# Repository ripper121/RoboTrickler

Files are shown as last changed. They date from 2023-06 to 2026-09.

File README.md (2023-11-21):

# RoboTrickler
 
If you like it, spend me a coffee :)

### Donation: [Paypal](https://www.paypal.com/donate/?hosted_button_id=UHZEEUSTRAF88) (paypal.me/ripper121)

### Full Manual: [Wiki](https://github.com/ripper121/RoboTrickler/wiki)

At the moment only in German, but DeepL will help you ;)

### Latest Release: [Download](https://github.com/ripper121/RoboTrickler/releases/latest)

Youtube:

youtube video (https://www.youtube.com/watch?v=XJgkiJFMUQI)

# License

## creative commons

# Attribution-NonCommercial-ShareAlike 4.0 International

Creative Commons Corporation (“Creative Commons”) is not a law firm and does not provide legal services or legal advice. Distribution of Creative Commons public licenses does not create a lawyer-client or other relationship. Creative Commons makes its licenses and related information available on an “as-is” basis. Creative Commons gives no warranties regarding its licenses, any material licensed under their terms and conditions, or any related information. Creative Commons disclaims all liability for damages resulting from their use to the fullest extent possible.

### Using Creative Commons Public Licenses

Creative Commons public licenses provide a standard set of terms and conditions that creators and other rights holders may use to share original works of authorship and other material subject to copyright and certain other rights specified in the public license below. The following considerations are for informational purposes only, are not exhaustive, and do not form part of our licenses.

* __Considerations for licensors:__ Our public licenses are intended for use by those authorized to give the public permission to use material in ways otherwise restricted by copyright and certain other rights. Our licenses are irrevocable. Licensors should read and understand the terms and conditions of the license they choose before applying it. Licensors should also secure all rights necessary before applying our licenses so that the public can reuse the material as expected. Licensors should clearly mark any material not subject to the license. This includes other CC-licensed material, or material used under an exception or limitation to copyright. [More considerations for licensors](http://wiki.creativecommons.org/Considerations_for_licensors_and_licensees#Considerations_for_licensors).

* __Considerations for the public:__ By using one of our public licenses, a licensor grants the public permission to use the licensed material under specified terms and conditions. If the licensor’s permission is not necessary for any reason–for example, because of any applicable exception or limitation to copyright–then that use is not regulated by the license. Our licenses grant only permissions under copyright and certain other rights that a licensor has authority to grant. Use of the licensed material may still be restricted for other reasons, including because others have copyright or other rights in the material. A licensor may make special requests, such as asking that all changes be marked or described. Although not required by our licenses, you are encouraged to respect those requests where reasonable. [More considerations for the public](http://wiki.creativecommons.org/Considerations_for_licensors_and_licensees#Considerations_for_licensees).

## Creative Commons Attribution-NonCommercial-ShareAlike 4.0 International Public License

By exercising the Licensed Rights (defined below), You accept and agree to be bound by the terms and conditions of this Creative Commons Attribution-NonCommercial-ShareAlike 4.0 International Public License ("Public License"). To the extent this Public License may be interpreted as a contract, You are granted the Licensed Rights in consideration of Your acceptance of these terms and conditions, and the Licensor grants You such rights in consideration of benefits the Licensor receives from making the Licensed Material available under these terms and conditions.

### Section 1 – Definitions.

a. __Adapted Material__ means material subject to Copyright and Similar Rights that is derived from or based upon the Licensed Material and in which the Licensed Material is translated, altered, arranged, transformed, or otherwise modified in a manner requiring permission under the Copyright and Similar Rights held by the Licensor. For purposes of this Public License, where the Licensed Material is a musical work, performance, or sound recording, Adapted Material is always produced where the Licensed Material is synched in timed relation with a moving image.

b. __Adapter's License__ means the license You apply to Your Copyright and Similar Rights in Your contributions to Adapted Material in accordance with the terms and conditions of this Public License.

c. __BY-NC-SA Compatible License__ means a license listed at [creativecommons.org/compatiblelicenses](http://creativecommons.org/compatiblelicenses), approved by Creative Commons as essentially the equivalent of this Public License.

d. __Copyright and Similar Rights__ means copyright and/or similar rights closely related to copyright including, without limitation, performance, broadcast, sound recording, and Sui Generis Database Rights, without regard to how the rights are labeled or categorized. For purposes of this Public License, the rights specified in Section 2(b)(1)-(2) are not Copyright and Similar Rights.

e. __Effective Technological Measures__ means those measures that, in the absence of proper authority, may not be circumvented under laws fulfilling obligations under Article 11 of the WIPO Copyright Treaty adopted on December 20, 1996, and/or similar international agreements.

f. __Exceptions and Limitations__ means fair use, fair dealing, and/or any other exception or limitation to Copyright and Similar Rights that applies to Your use of the Licensed Material.

g. __License Elements__ means the license attributes listed in the name of a Creative Commons Public License. The License Elements of this Public License are Attribution, NonCommercial, and ShareAlike.

h. __Licensed Material__ means the artistic or literary work, database, or other material to which the Licensor applied this Public License.

i. __Licensed Rights__ means the rights granted to You subject to the terms and conditions of this Public License, which are limited to all Copyright and Similar Rights that apply to Your use of the Licensed Material and that the Licensor has authority to license.

j. __Licensor__ means the individual(s) or entity(ies) granting rights under this Public License.

k. __NonCommercial__ means not primarily intended for or directed towards commercial advantage or monetary compensation. For purposes of this Public License, the exchange of the Licensed Material for other material subject to Copyright and Similar Rights by digital file-sharing or similar means is NonCommercial provided there is no payment of monetary compensation in connection with the exchange.

l. __Share__ means to provide material to the public by any means or process that requires permission under the Licensed Rights, such as reproduction, public display, public performance, distribution, dissemination, communication, or importation, and to make material available to the public including in ways that members of the public may access the material from a place and at a time individually chosen by them.

m. __Sui Generis Database Rights__ means rights other than copyright resulting from Directive 96/9/EC of the European Parliament and of the Council of 11 March 1996 on the legal protection of databases, as amended and/or succeeded, as well as other essentially equivalent rights anywhere in the world.

n. __You__ means the individual or entity exercising the Licensed Rights under this Public License. Your has a corresponding meaning.

### Section 2 – Scope.

a. ___License grant.___

   1. Subject to the terms and conditions of this Public License, the Licensor hereby grants You a worldwide, royalty-free, non-sublicensable, non-exclusive, irrevocable license to exercise the Licensed Rights in the Licensed Material to:

        A. reproduce and Share the Licensed Material, in whole or in part, for NonCommercial purposes only; and

        B. produce, reproduce, and Share Adapted Material for NonCommercial purposes only.

   2. __Exceptions and Limitations.__ For the avoidance of doubt, where Exceptions and Limitations apply to Your use, this Public License does not apply, and You do not need to comply with its terms and conditions.

   3. __Term.__ The term of this Public License is specified in Section 6(a).

   4. __Media and formats; technical modifications allowed.__ The Licensor authorizes You to exercise the Licensed Rights in all media and formats whether now known or hereafter created, and to make technical modifications necessary to do so. The Licensor waives and/or agrees not to assert any right or authority to forbid You from making technical modifications necessary to exercise the Licensed Rights, including technical modifications necessary to circumvent Effective Technological Measures. For purposes of this Public License, simply making modifications authorized by this Section 2(a)(4) never produces Adapted Material.

   5. __Downstream recipients.__

        A. __Offer from the Licensor – Licensed Material.__ Every recipient of the Licensed Material automatically receives an offer from the Licensor to exercise the Licensed Rights under the terms and conditions of this Public License.

        B. __Additional offer from the Licensor – Adapted Material.__ Every recipient of Adapted Material from You automatically receives an offer from the Licensor to exercise the Licensed Rights in the Adapted Material under the conditions of the Adapter’s License You apply.

        C. __No downstream restrictions.__ You may not offer or impose any additional or different terms or conditions on, or apply any Effective Technological Measures to, the Licensed Material if doing so restricts exercise of the Licensed Rights by any recipient of the Licensed Material.

   6. __No endorsement.__ Nothing in this Public License constitutes or may be construed as permission to assert or imply that You are, or that Your use of the Licensed Material is, connected with, or sponsored, endorsed, or granted official status by, the Licensor or others designated to receive attribution as provided in Section 3(a)(1)(A)(i).

b. ___Other rights.___

   1. Moral rights, such as the right of integrity, are not licensed under this Public License, nor are publicity, privacy, and/or other similar personality rights; however, to the extent possible, the Licensor waives and/or agrees not to assert any such rights held by the Licensor to the limited extent necessary to allow You to exercise the Licensed Rights, but not otherwise.

   2. Patent and trademark rights are not licensed under this Public License.

   3. To the extent possible, the Licensor waives any right to collect royalties from You for the exercise of the Licensed Rights, whether directly or through a collecting society under any voluntary or waivable statutory or compulsory licensing scheme. In all other cases the Licensor expressly reserves any right to collect such royalties, including when the Licensed Material is used other than for NonCommercial purposes.

### Section 3 – License Conditions.

Your exercise of the Licensed Rights is expressly made subject to the following conditions.

a. ___Attribution.___

   1. If You Share the Licensed Material (including in modified form), You must:

       A. retain the following if it is supplied by the Licensor with the Licensed Material:

         i. identification of the creator(s) of the Licensed Material and any others designated to receive attribution, in any reasonable manner requested by the Licensor (including by pseudonym if designated);

         ii. a copyright notice;

         iii. a notice that refers to this Public License;

         iv. a notice that refers to the disclaimer of warranties;

         v. a URI or hyperlink to the Licensed Material to the extent reasonably practicable;

       B. indicate if You modified the Licensed Material and retain an indication of any previous modifications; and

       C. indicate the Licensed Material is licensed under this Public License, and include the text of, or the URI or hyperlink to, this Public License.

   2. You may satisfy the conditions in Section 3(a)(1) in any reasonable manner based on the medium, means, and context in which You Share the Licensed Material. For example, it may be reasonable to satisfy the conditions by providing a URI or hyperlink to a resource that includes the required information.

   3. If requested by the Licensor, You must remove any of the information required by Section 3(a)(1)(A) to the extent reasonably practicable.

b. ___ShareAlike.___

In addition to the conditions in Section 3(a), if You Share Adapted Material You produce, the following conditions also apply.

1. The Adapter’s License You apply must be a Creative Commons license with the same License Elements, this version or later, or a BY-NC-SA Compatible License.

2. You must include the text of, or the URI or hyperlink to, the Adapter's License You apply. You may satisfy this condition in any reasonable manner based on the medium, means, and context in which You Share Adapted Material.

3. You may not offer or impose any additional or different terms or conditions on, or apply any Effective Technological Measures to, Adapted Material that restrict exercise of the rights granted under the Adapter's License You apply.

### Section 4 – Sui Generis Database Rights.

Where the Licensed Rights include Sui Generis Database Rights that apply to Your use of the Licensed Material:

a. for the avoidance of doubt, Section 2(a)(1) grants You the right to extract, reuse, reproduce, and Share all or a substantial portion of the contents of the database for NonCommercial purposes only;

b. if You include all or a substantial portion of the database contents in a database in which You have Sui Generis Database Rights, then the database in which You have Sui Generis Database Rights (but not its individual contents) is Adapted Material, including for purposes of Section 3(b); and

c. You must comply with the conditions in Section 3(a) if You Share all or a substantial portion of the contents of the database.

For the avoidance of doubt, this Section 4 supplements and does not replace Your obligations under this Public License where the Licensed Rights include other Copyright and Similar Rights.

### Section 5 – Disclaimer of Warranties and Limitation of Liability.

a. __Unless otherwise separately undertaken by the Licensor, to the extent possible, the Licensor offers the Licensed Material as-is and as-available, and makes no representations or warranties of any kind concerning the Licensed Material, whether express, implied, statutory, or other. This includes, without limitation, warranties of title, merchantability, fitness for a particular purpose, non-infringement, absence of latent or other defects, accuracy, or the presence or absence of errors, whether or not known or discoverable. Where disclaimers of warranties are not allowed in full or in part, this disclaimer may not apply to You.__

b. __To the extent possible, in no event will the Licensor be liable to You on any legal theory (including, without limitation, negligence) or otherwise for any direct, special, indirect, incidental, consequential, punitive, exemplary, or other losses, costs, expenses, or damages arising out of this Public License or use of the Licensed Material, even if the Licensor has been advised of the possibility of such losses, costs, expenses, or damages. Where a limitation of liability is not allowed in full or in part, this limitation may not apply to You.__

c. The disclaimer of warranties and limitation of liability provided above shall be interpreted in a manner that, to the extent possible, most closely approximates an absolute disclaimer and waiver of all liability.

### Section 6 – Term and Termination.

a. This Public License applies for the term of the Copyright and Similar Rights licensed here. However, if You fail to comply with this Public License, then Your rights under this Public License terminate automatically.

b. Where Your right to use the Licensed Material has terminated under Section 6(a), it reinstates:

   1. automatically as of the date the violation is cured, provided it is cured within 30 days of Your discovery of the violation; or

   2. upon express reinstatement by the Licensor.

   For the avoidance of doubt, this Section 6(b) does not affect any right the Licensor may have to seek remedies for Your violations of this Public License.

c. For the avoidance of doubt, the Licensor may also offer the Licensed Material under separate terms or conditions or stop distributing the Licensed Material at any time; however, doing so will not terminate this Public License.

d. Sections 1, 5, 6, 7, and 8 survive termination of this Public License.

### Section 7 – Other Terms and Conditions.

a. The Licensor shall not be bound by any additional or different terms or conditions communicated by You unless expressly agreed.

b. Any arrangements, understandings, or agreements regarding the Licensed Material not stated herein are separate from and independent of the terms and conditions of this Public License.

### Section 8 – Interpretation.

a. For the avoidance of doubt, this Public License does not, and shall not be interpreted to, reduce, limit, restrict, or impose conditions on any use of the Licensed Material that could lawfully be made without permission under this Public License.

b. To the extent possible, if any provision of this Public License is deemed unenforceable, it shall be automatically reformed to the minimum extent necessary to make it enforceable. If the provision cannot be reformed, it shall be severed from this Public License without affecting the enforceability of the remaining terms and conditions.

c. No term or condition of this Public License will be waived and no failure to comply consented to unless expressly agreed to by the Licensor.

d. Nothing in this Public License constitutes or may be interpreted as a limitation upon, or waiver of, any privileges and immunities that apply to the Licensor or You, including from the legal processes of any jurisdiction or authority.

> Creative Commons is not a party to its public licenses. Notwithstanding, Creative Commons may elect to apply one of its public licenses to material it publishes and in those instances will be considered the “Licensor.” The text of the Creative Commons public licenses is dedicated to the public domain under the CC0 Public Domain Dedication. Except for the limited purpose of indicating that material is shared under a Creative Commons public license or as otherwise permitted by the Creative Commons policies published at creativecommons.org/policies, Creative Commons does not authorize the use of the trademark “Creative Commons” or any other trademark or logo of Creative Commons without its prior written consent including, without limitation, in connection with any unauthorized modifications to any of its public licenses or any other arrangements, understandings, or agreements concerning use of licensed material. For the avoidance of doubt, this paragraph does not form part of the public licenses.
>
> Creative Commons may be contacted at creativecommons.org

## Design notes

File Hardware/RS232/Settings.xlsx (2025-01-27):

 | G&G | Steinberg | KERN | Sartorius 9PIN | Sartorius 25PIN | Acculab 25PIN | A&D
RS_1 |  |  |  |  |  |  | X
RS_2 | X | X | X | X | X | X
RS_3_R |  |  |  |  |  |  | X
RS_3_L | X | X | X | X | X | X
RS_4 |  |  |  |  |  |  | X
RS_5 | X | X | X | X | X | X
RXD | L | L | R | L | R | R | L
TXD | R | R | L | R | L | L | R
Connector | Male | Male | Male | Female | Female | Female | Female

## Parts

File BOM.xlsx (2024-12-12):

Menge | Bezeichnung | Bezugsquelle
1 | MKS DLC32-TS35 | https://www.amazon.de/KOOKYE-Printer-TS35-R-Offline-Controller/dp/B09N3HH27T
1 | MKS TS35 | https://www.amazon.de/KOOKYE-Controller-engraving-Alternate-versions/dp/B09J21K33F
1 | A4988 | https://shop.strenuous.dev/Motor-Treiber-A4988/P8
1 | MKS DLC32 Enclosure or 3D Print | https://www.aliexpress.com/item/32872172334.html
2 | Rillenkugellager 6900RS 10mmx22mmx6mm | https://www.amazon.de/sourcing-map-Rillenkugellager-10mmx22mmx6mm-Kohlenstoffstahl/dp/B07H5J1JD6
1 | Nema 17 Schrittmotor 42x23mm | https://www.amazon.de/dp/B08FFKZLYH
1 | Alurohr 10x 8 x 160mm | https://shop.strenuous.dev/Alurohr-160mm/P15
1 | 12 V DC 2 A 24 W Netzteil | https://www.amazon.de/dp/B01G0Q3RWU
1 | 4 Pin Dupont / Jumper Kabel female | https://shop.strenuous.dev/RS232-Kabel/P11
1 | RS232 TTL Konverter Stecker | https://shop.strenuous.dev/RS232-Stecker/P19.11
5 | M3 x 6mm | https://shop.strenuous.dev/M3x6-Linsenkopf-Schraube/P14
1 | 3D Druckteile | https://shop.strenuous.dev/3D-Druck-Teile/P16
 | Komplett Bausatz | https://shop.strenuous.dev/Robo-Trickler/P1.2 | 175.00 €
 | Fertig aufgebaut & Getesetet | https://shop.strenuous.dev/Robo-Trickler/P1.1 | 275.00 €
 | Passende Waagen:
 | G&G PLC 100 | https://waage-shop.com/PLC-Feinwaagen-Tischwaage-Praezisionswaagen | 115.00 €
 | G&G JJ100B Empfehlung für schnelles Trickeln | https://waage-shop.com/JJ-B-Praezisionwaage-Laborwaage-JJ100B-110g-0001g | 240.00 €
 | Oder jede ander mit RS232

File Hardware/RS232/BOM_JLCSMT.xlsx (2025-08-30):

Comment | Designator | Footprint | JLCPCB Part #（optional）
1000uF | C5 | 140CLH-1010 | C72469
RED | RXD | CHIP-LED0603 | C2286
B6B-PH-K-S(LF)(SN) | TTL | Through Hole,P=2mm | C131342
GREEN | TXD | CHIP-LED0603 | C2286
1k | R1,R2 | R0402 | C11702
100n | C1,C2,C3,C4 | C0402 | C1525
SP3232EEN-L/TR | U1 | SOIC127P600X175-16N | C13482
PINHD-2X3 | JP1 | 2X03 | C65114
Amphenol ICC LD09P13A4GX00LF | RS232 | D-Sub | C3118153

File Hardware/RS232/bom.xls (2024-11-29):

Comment | Designator | Footprint | JLCPCB Part #
RED | RXD | CHIP-LED0603 | C2286
PINHD-1X4/90 | TTL | 1X04/90 | C492412
GREEN | TXD | CHIP-LED0603 | C72043
1k | R1,R2 | R0402 | C11702
SP3232EEN-L/TR | U1 | SOIC127P600X175-16N | C13482
100n | C1,C2,C3,C4 | C0402 | C1525
PINHD-2X3 | JP1 | 2X03 | C7501274
AmphenolICCLD09P13A4GX00LF | RS232 | D-Sub | C3103673

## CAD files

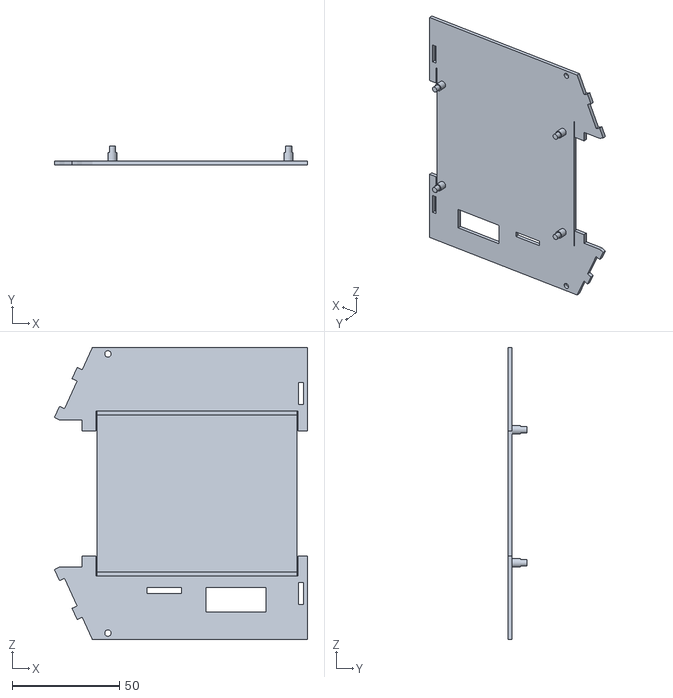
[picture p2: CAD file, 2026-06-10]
Hardware/CAD/Housing/Main.stl
118.0 x 9.00 x 136.0

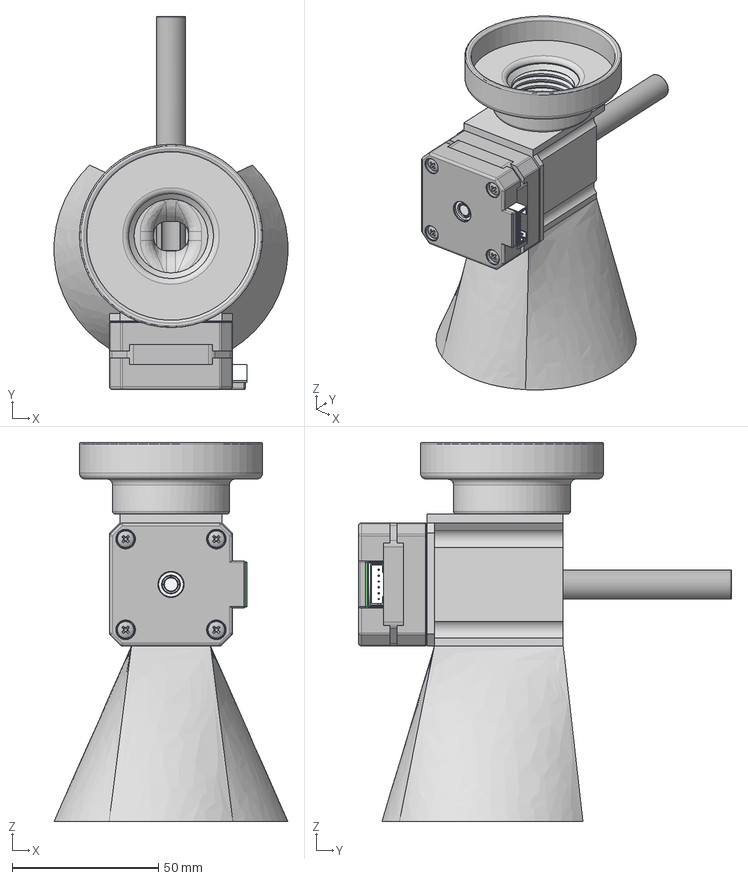
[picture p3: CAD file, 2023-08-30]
3D-Files/Trickler_Full.step
79.9 x 127.6 x 129.5 mm
61900-2rs1 x 2
M3x12-Screw
M3x12-Screw004
M3x12-Screw005
M3x12-Screw006

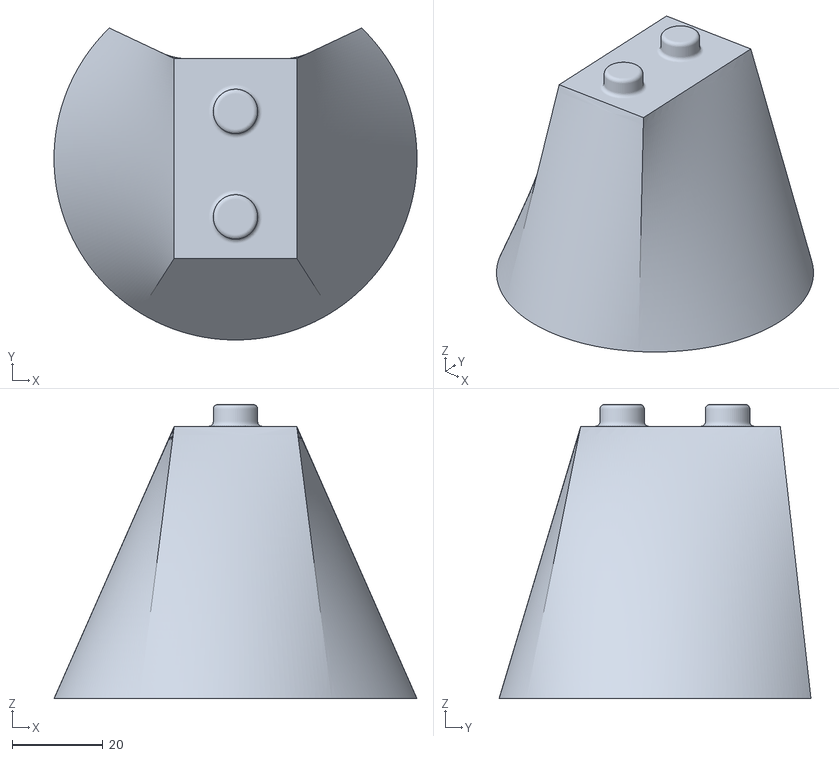
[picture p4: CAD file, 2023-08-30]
3D-Files/Base.stl
80.0 x 68.8 x 64.8

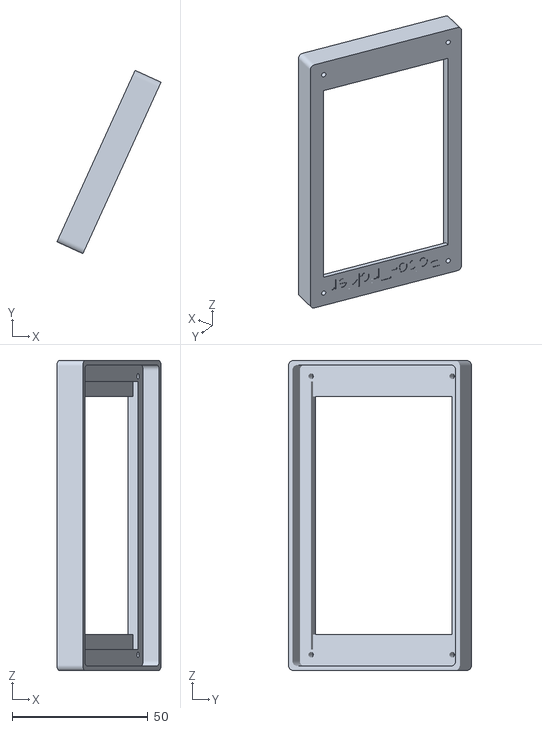
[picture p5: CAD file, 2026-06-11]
Hardware/CAD/Housing/Display1.stl
38.3 x 67.4 x 114.0

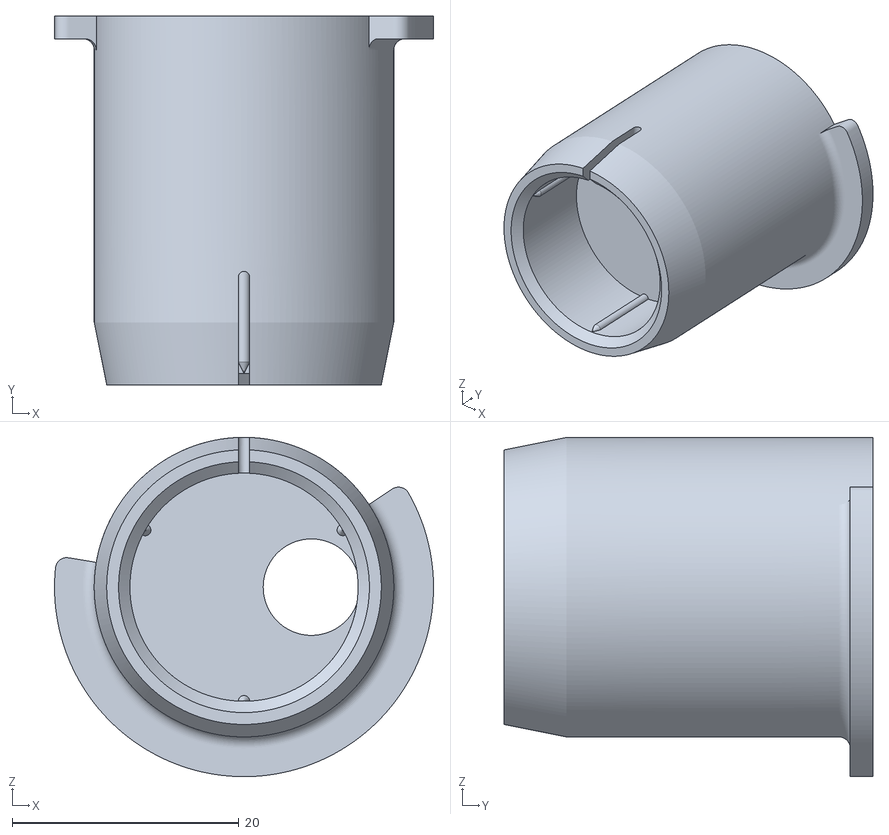
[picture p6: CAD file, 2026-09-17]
Hardware/CAD/Trickler/Lee.stl
33.4 x 32.5 x 29.9

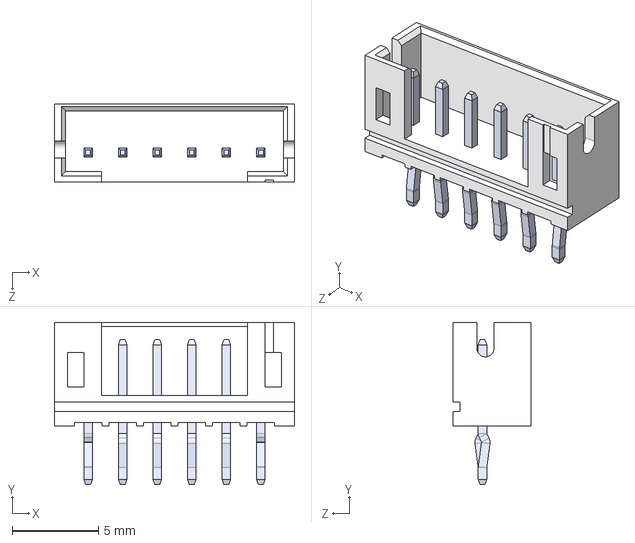
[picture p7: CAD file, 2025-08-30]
Hardware/RS232/B6B-PH-K-S(LF)(SN).STEP
13.9 x 9.40 x 4.50 mm

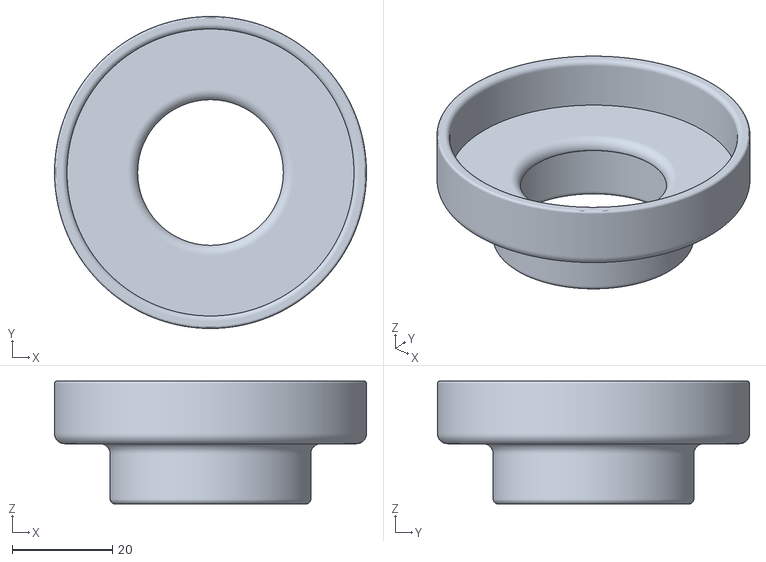
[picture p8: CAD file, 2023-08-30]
3D-Files/Cap.stl
62.2 x 62.2 x 24.5

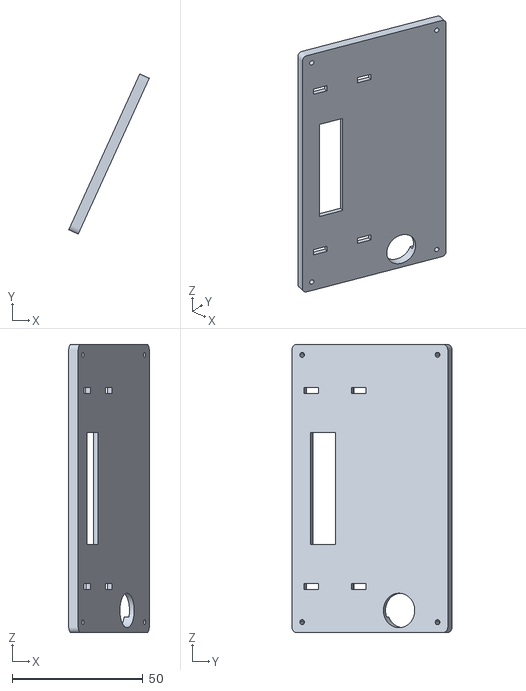
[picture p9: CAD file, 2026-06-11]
Hardware/CAD/Housing/Display0.stl
30.8 x 61.4 x 110.3

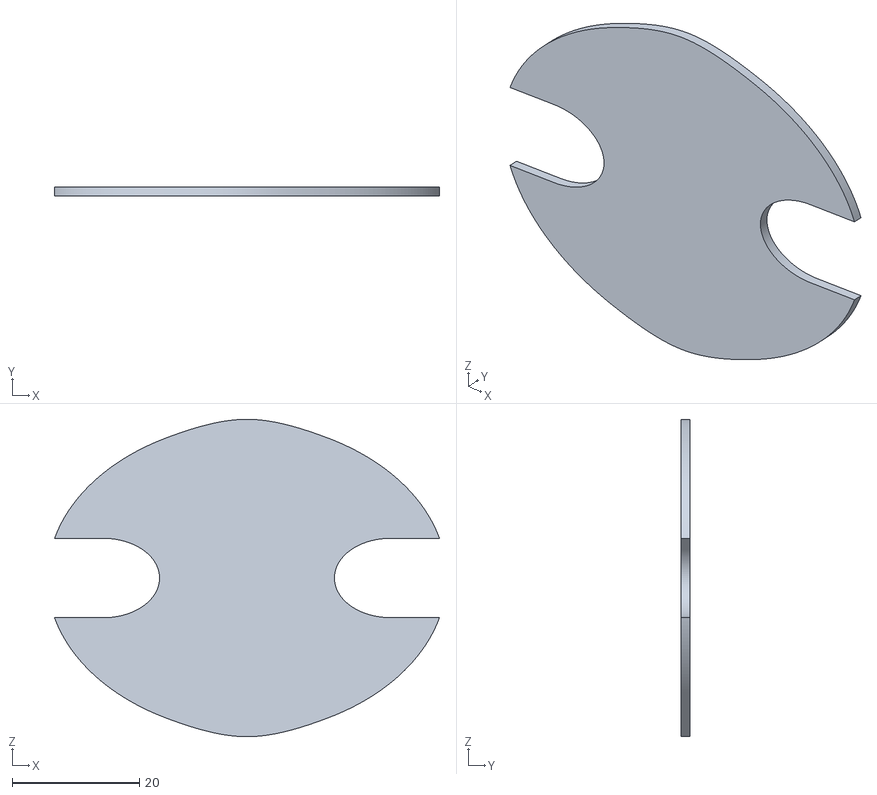
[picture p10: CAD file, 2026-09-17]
Hardware/CAD/Trickler/RoofLee.stl
60.6 x 1.47 x 49.9

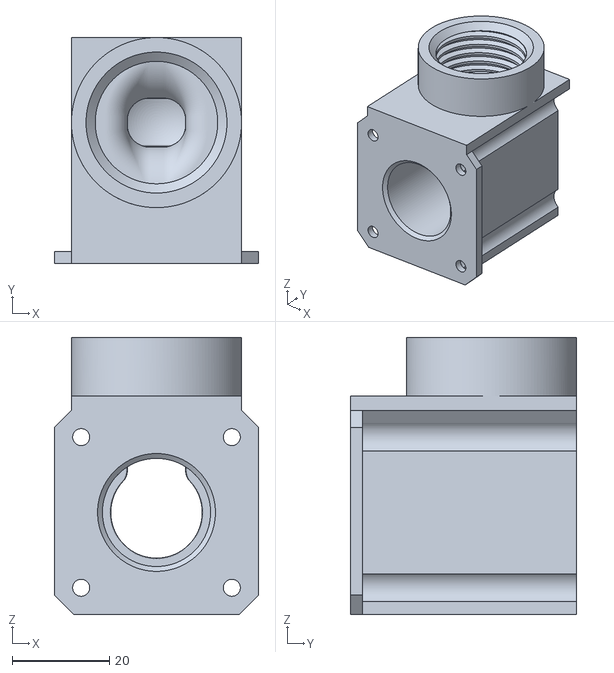
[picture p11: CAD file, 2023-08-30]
3D-Files/Trickler_Body_Base.stl
42.0 x 46.5 x 57.0

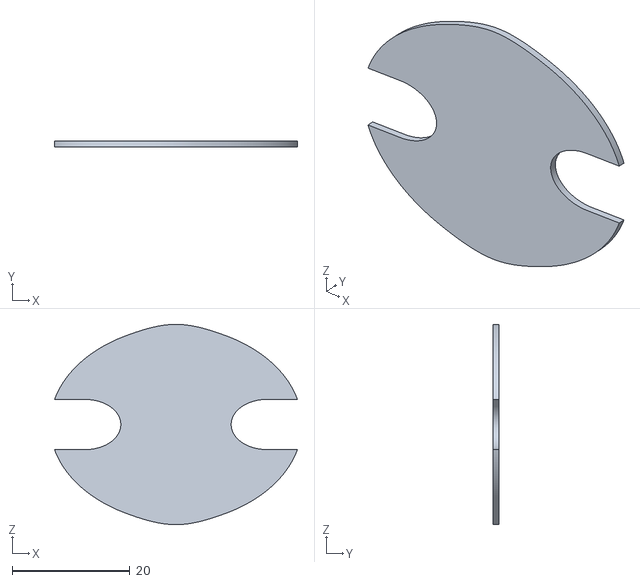
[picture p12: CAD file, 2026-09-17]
Hardware/CAD/Trickler/Roof.stl
41.2 x 1.00 x 34.0

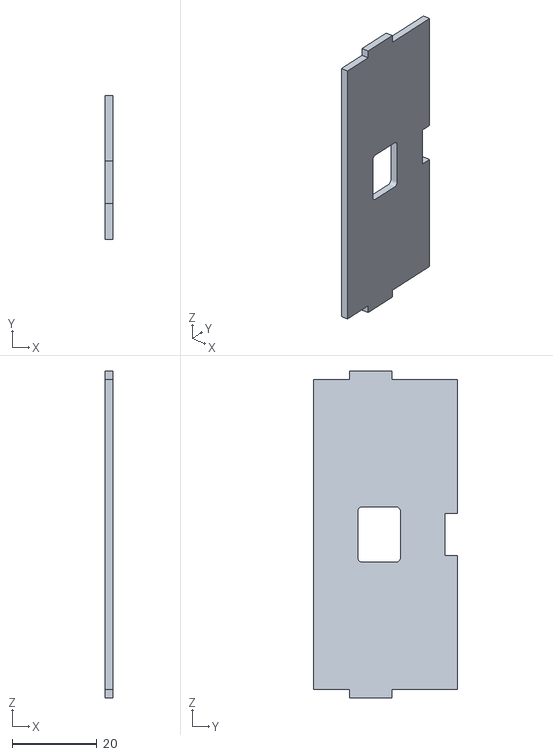
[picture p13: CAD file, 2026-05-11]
Hardware/CAD/Housing/Back.stl
2.00 x 34.0 x 77.0

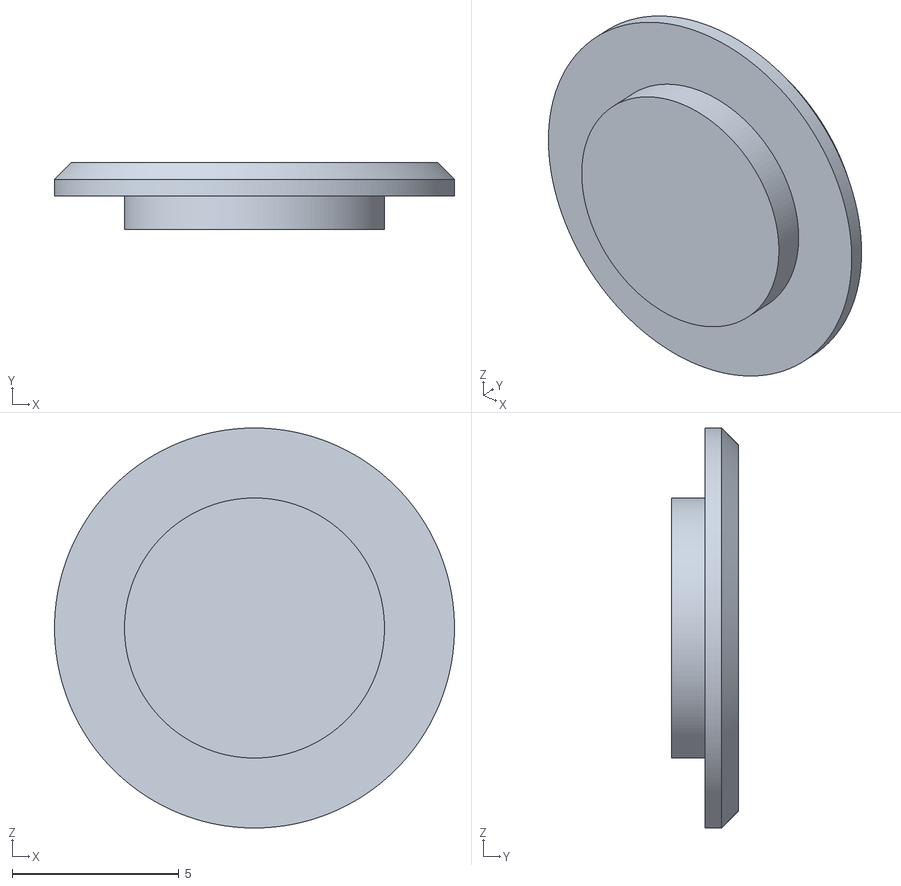
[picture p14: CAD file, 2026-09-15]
Hardware/CAD/Trickler/StandCap.stl
12.0 x 2.00 x 12.0

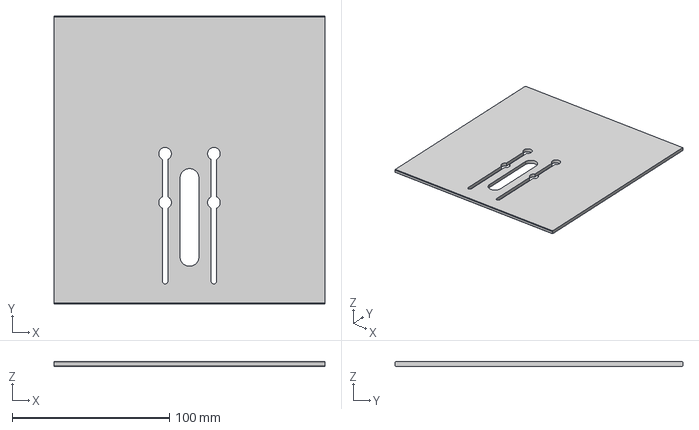
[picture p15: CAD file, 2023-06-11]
3D-Files/GuG_Back.step
172.0 x 183.0 x 3.00 mm

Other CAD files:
Hardware/CAD/Housing/Top.stl
Hardware/CAD/Trickler/Stand.stl
Hardware/CAD/Trickler/MotorPipeJoin.stl
Hardware/CAD/Trickler/Body.stl
3D-Files/GuG_Back.f3d
3D-Files/GuG_Back.stl
3D-Files/Trickler_Full.f3z
3D-Files/Trickler_Full_GUG.f3z
Hardware/CAD/OldVersion/3D-Files/Mods/Awacs-Mod/Robo-Trickler mod Awacs/Body mod Awacs.stp
Hardware/CAD/OldVersion/3D-Files/Mods/Awacs-Mod/Robo-Trickler mod Awacs/Coupler.stp
Hardware/CAD/OldVersion/3D-Files/Mods/Awacs-Mod/Robo-Trickler mod Awacs/Funnel.stp
Hardware/CAD/OldVersion/3D-Files/Mods/Awacs-Mod/Robo-Trickler mod Awacs/MKS DLC32 2.1 Case Body bot.stp
Hardware/CAD/OldVersion/3D-Files/Mods/Awacs-Mod/Robo-Trickler mod Awacs/MKS DLC32 2.1 Case Body top.stp
Hardware/CAD/OldVersion/3D-Files/Mods/Awacs-Mod/Robo-Trickler mod Awacs/MKS TS35 Case Bot.stp
Hardware/CAD/OldVersion/3D-Files/Mods/Awacs-Mod/Robo-Trickler mod Awacs/MKS TS35 Case Top.stp
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

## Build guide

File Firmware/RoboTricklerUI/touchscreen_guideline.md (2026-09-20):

# Touchscreen Design Guidelines

- https://learn.microsoft.com/en-us/windows/apps/develop/input/guidelines-for-targeting
- https://learn.microsoft.com/en-us/windows/win32/uxguide/inter-touch
- https://developer.apple.com/design/human-interface-guidelines/
- https://developer.apple.com/design/tips/
- https://www.w3.org/WAI/WCAG22/Understanding/target-size-minimum
- https://www.w3.org/TR/WCAG22/#target-size-minimum
- https://www.iso.org/standard/77520.html
- https://www.iso.org/ics/13.180/x/
- https://webstore.iec.ch/en/publication/624
- https://webstore.iec.ch/en/publication/2186
- https://webstore.iec.ch/en/publication/71256

## Review scope and source findings (2026-09-19)

Every URL above was opened and its available content reviewed. The two Microsoft
articles, Apple design tips, and the W3C target-size pages provide directly
usable guidance. The Apple HIG and ISO ergonomics pages are indexes, so their
relevant topics are distinguished below from the index itself. ISO/IEC catalog
pages are not the full standards: the paid normative texts were not available
in the project and were not purchased. No certification or full platform/WCAG
conformance is claimed by this GUI update.

### 1. Microsoft: Guidelines for touch targets

[Source](https://learn.microsoft.com/en-us/windows/apps/develop/input/guidelines-for-targeting).
A physical target around 7.5 mm is the general recommendation (the example uses
40 pixels at 135 PPI). Frequency, consequence of an error, position, screen
size, posture and feedback should influence the final size. Frequent actions
can be larger; consequential actions need additional separation from edges.
**Application:** keep the full-width run control, use 44-pixel minimum visible
buttons, inset controls, and preserve confirmation before deleting or replacing
stored data. Physical dimensions still depend on the actual panel.

### 2. Microsoft: Touch (Win32)

[Source](https://learn.microsoft.com/en-us/windows/win32/uxguide/inter-touch).
This is older Windows guidance, not a current embedded-device specification.
It covers familiar gestures, immediate feedback, forgiving controls, safe
defaults, constrained input, target sizes and spacing. Its custom-control advice
uses 7 mm generally, 9 mm when mistakes are harder to correct, and a limited
5 mm fallback with 2 mm spacing. It recommends at least 5 pixels between
interactive controls in its Windows layout context, larger frequent commands,
nearby related controls, and avoiding small edge targets. Hover must not be
required; a tap ends on release. Keyboard, text-entry, multi-touch rotation,
zoom and Windows shell guidance apply only where those features exist.
**Application:** LVGL buttons, release activation, slide-off cancellation, nearby
value adjustment controls, visible unavailable states, and no added keyboard,
custom gesture, zoom or rotation dependency.

### 3. Apple: Human Interface Guidelines

[HIG index](https://developer.apple.com/design/human-interface-guidelines/).
The landing page organizes design principles, foundations and platform topics;
it is not itself a single touchscreen specification. Its official documentation
JSON was read because the HTML landing page requires JavaScript. Relevant
chapters reviewed:

- [Design principles](https://developer.apple.com/design/human-interface-guidelines/design-principles):
  familiar behavior, clear feedback, recoverable mistakes, concise wording,
  hierarchy and iterative evaluation. Apply these to the existing task flow.
- [Accessibility](https://developer.apple.com/design/human-interface-guidelines/accessibility):
  use more than color or sound alone, sufficient contrast and spacing, simple
  gestures, visible alternatives, and explicit dismissal. The current table
  distinguishes recommended/default control sizes from smaller platform minima;
  those are Apple points. VoiceOver, Dynamic Type, speech and switch integration
  are Apple platform features, not capabilities supplied by this firmware.
- [Layout](https://developer.apple.com/design/human-interface-guidelines/layout):
  group related actions, preserve hierarchy and safe areas, and test text lengths
  and clipping in different localizations. Fixed hardware does not need Apple
  window size classes or Liquid Glass, but it still needs bounds checks.
- [Buttons](https://developer.apple.com/design/human-interface-guidelines/buttons):
  recognizable purpose, a pressed state, clear short labels, and consistent
  related choices. Use descriptive text where an isolated symbol is ambiguous.
- [Alerts](https://developer.apple.com/design/human-interface-guidelines/alerts):
  reserve interruptions for useful decisions, state the consequence briefly,
  name the action and provide an explicit cancellation. Prefer short messages
  that fit; allow scrolling here as a fallback for filenames and translations.
  Keep this device's established action positions and save/cancel colors rather
  than imposing Apple-specific button order on an existing embedded interface.
- [Gestures](https://developer.apple.com/design/human-interface-guidelines/gestures):
  familiar gestures, responsive feedback, visibly unavailable actions and tap
  alternatives to custom gestures. Keep tab buttons and tuning arrows; no action
  should depend on discovering a swipe.

### 4. Apple: UI Design Dos and Don'ts

[Source](https://developer.apple.com/design/tips/).
The page covers content fitting the screen, touch controls, 44 x 44 point hit
regions, text of at least 11 points, text/background contrast, non-overlapping
text, appropriate image resolution and aspect ratio, related-control grouping,
and alignment. These platform points are not firmware pixels.
**Application:** retain the existing 18/34-pixel fonts and crisp built-in symbols,
keep the QR square, improve bright-button contrast, fit labels and buttons inside
the display, and check both English and German. No raster artwork is needed.

### 5. W3C: Understanding Target Size (Minimum)

[Source](https://www.w3.org/WAI/WCAG22/Understanding/target-size-minimum).
This explains SC 2.5.8 and its benefits for people with reduced pointer accuracy.
The target must contain an axis-aligned 24 x 24 CSS-pixel square, or qualify for
an exception. For undersized targets, the spacing test places a 24-pixel-diameter
circle at each target's bounding-box center; it must avoid other targets and
such circles. Size refers to the usable target, including clipping and shape,
not merely a declared rectangle. Newly opened overlays also need usable targets.
**Application:** inspect actual LVGL rectangles and ancestor clipping, including
lazy dialogs; do not use invisible hit-area expansion across neighboring controls.

### 6. W3C: WCAG 2.2, SC 2.5.8

[Normative target-size section](https://www.w3.org/TR/WCAG22/#target-size-minimum).
The AA requirement is 24 x 24 CSS pixels, with spacing, equivalent-control,
inline, user-agent-control and essential-presentation exceptions. SC 2.5.5 uses
44 x 44 CSS pixels at AAA. Related sections reviewed include release/cancellation
(2.5.2), color independence (1.4.1), contrast (1.4.3 and 1.4.11), labels (3.3.2),
and consistent identification (3.2.4). Text contrast guidance uses 4.5:1 normally
and 3:1 for large text; meaningful control graphics use 3:1 with exceptions.
**Application:** use these as design checks, not a web-conformance assertion.
The native panel has no CSS pixel mapping, browser accessibility tree, keyboard
navigation or screen-reader implementation. Do not claim those from larger buttons.

### 7. ISO 9241-210:2019

[Catalog and abstract](https://www.iso.org/standard/77520.html).
This concerns human-centred design throughout an interactive system's lifecycle.
It is a process framework rather than a pixel-size rule; the abstract explicitly
separates detailed ergonomics and health/safety treatment. The full normative
text is not available here. **Application:** record context, findings and test
limitations; use representative operating tasks to evaluate the result. This is
an engineering application of the public scope, not a clause-by-clause ISO audit.

### 8. ISO ICS 13.180: Ergonomics

[Catalog index](https://www.iso.org/ics/13.180/x/).
This lists many ergonomics standards and their status, including ISO 9241 parts;
it contains no single set of UI requirements. **Application:** treat it as a
bibliography for further hardware/usability work, not a source of invented
minimum pixel dimensions. Reading the index does not mean all listed standards
have been obtained or read.

### 9. IEC publication 624

[Catalog](https://webstore.iec.ch/en/publication/624).
The link resolves to IEC 60079-11:2011/ISH1:2014, an interpretation sheet about
intrinsically safe equipment in explosive atmospheres. The catalog marks it
revised/withdrawn and links a newer publication. **Application:** no touchscreen
layout rule can be derived from this page. No electrical protection or device
safety claim follows from UI styling.

### 10. IEC publication 2186

[Catalog and abstract](https://webstore.iec.ch/en/publication/2186).
This is IEC 60455-3-5:2006, about unsaturated polyester impregnating resins for
electrical insulation, including elevated-temperature properties. It is not a
touchscreen/HMI design document. **Application:** none to LVGL layout; retain the
link with this correction so it is not mistaken for a touch-target standard.

### 11. IEC publication 71256

[Catalog and abstract](https://webstore.iec.ch/en/publication/71256).
IEC 60204-1:2016+AMD1:2021 concerns electrical equipment of machines. The public
summary mentions drive systems, protection, bonding, emergency-stop/control
circuits, actuator symbols and technical documentation. It does not publish a
button-size rule. The full standard is not available here. **Application:** keep
this GUI work separate from electrical design verification; the on-screen Stop
command is an operating control, not a certified emergency-stop system.

## Device requirements derived from the findings

The existing hardware is 480 x 320 with configured `LV_DPI_DEF=130`. A 44-pixel
square is about 8.6 mm **if that configured density matches the physical panel**.
That conversion is an estimate, not a measurement. `ui_touch.h` centralizes the
44-pixel target and 8-pixel spacing choices. The gap is about 1.6 mm at that density;
it is not a claim to satisfy the older 2 mm exception for tiny targets, which
this design does not use. Adjacent tabs form one conventional segmented row.

| Finding | UI requirement / implementation |
| --- | --- |
| Target size and edge clearance | At least 44 x 44 visible button pixels; inset pages, profile actions and dialogs; no overlapping hit areas. |
| Readable hierarchy and alignment | Stable three-tab organization, adjacent value controls, complete primary weights, and labels contained within parents. |
| Clear purpose | Use standard symbols for unambiguous actions: sync, motor move, OK, close, copy, delete, create and Save. Keep state/value selectors as text, and state Flash/SD direction in the confirmation. |
| State feedback | Keep theme pressed/disabled feedback; visibly disable target adjustment while running instead of accepting a tap with no result. |
| Mistake recovery | Activate on release; slide outside to cancel; retain explicit confirmation for profile deletion and filesystem replacement. |
| Contrast and multiple cues | Black content on bright green/red/orange buttons; distinct text/symbols as well as colors; do not rely on beeps alone. |
| Complete decisions | Keep confirmation text concise where possible; wrap and vertically scroll long messages above fixed actions. |
| Localization | Test shipped English/German strings and long profile names; preserve language keys and storage/HTTP contracts. |
| Resource limits | Reuse LVGL buttons, labels, containers and shared styles; keep 24 KiB pool, fonts and enabled widgets unchanged. |

The installed ESP32 core (3.3.11), LVGL (9.5.0), local button/tabview/label/style/
scrolling examples, TFT touch integration and ESP-IDF LCD example index were
reviewed. Existing LVGL facilities supply the needed behavior; no new widget,
input driver, screen framework or image asset is needed. The scroll viewport is
one temporary container, destroyed with its message dialog.

## Verification

`python tools/ui_verify_layout.py` passed using the installed LVGL 9.5.0 and
32-bit MSVC. The harness compiles the actual `ui.c`, `ui_Screen1.c`, `ui_touch.c`
and extracts the current dialog factory bodies, avoiding a separately maintained
mock layout. Hardware callbacks only increment counters. It checks all three
tabs and opens all four tuning modes from the Profile tab in English/German,
including draw-memory headroom and immediate allocation recovery before another
dialog can open. It also checks minimum button size, ancestor clipping, 8-pixel
button separation, button text fit, release-only activation, slide into a
gap/neighbor cancellation, disabled target edits, modal blocking, long-message
scrolling with fixed actions, and allocation recovery over twenty message-dialog
lifecycles. Generated PNG previews in `%TEMP%/rtui_touch_audit`
were visually inspected for the main screen, Info, profile, German tuning and
long confirmation message.

The native harness uses one circle-cache entry because MSVC rejects LVGL's
zero-length GCC cache array; this override exists only in its generated config.
It retains the 24 KiB configured pool and enabled widgets. The monitor reported
21,748 managed bytes, an 18,280-byte peak and 13,524 bytes after dialogs closed.
The opaque modal backdrop prevents LVGL from also drawing the covered page, and
dialogs free synchronously so a result message cannot overlap the previous dialog.
Fixed Tune-button symbols use LVGL's background-symbol support, following its
spinbox example, which removes seven child-label objects. Redundant button
opacity and inherited-font/alignment properties are also omitted. The largest
free block during the Profile-to-Tune draw path is 4,384 bytes.
These are native harness measurements, not ESP32 runtime heap measurements.
The default blue was darkened for small white labels; bright green/red/orange
buttons retain black content. Existing red cancel and green save conventions
are preserved, with each action expanded to nearly half the tuning dialog width.

Firmware compile and image generation passed with
`python tools/firmware_build_upload.py --cli --error --compile-only`; the older `tools/compile_upload.py` named in `agents.md` is not
present. SD JSON parse validation and `git diff --check` passed. `lv_conf.h` is
unchanged. No device flash or electrical-standard certification was performed.
Native LVGL rendering can verify pixel bounds, text fit, state and synthetic
pointer behavior. It cannot establish actual finger accuracy, panel contrast,
Wi-Fi timing or ESP32 peak heap usage.

Physical-device follow-up: exercise all tabs and tuning modes with a finger,
including `100`, the motor-move action, save/cancel and both sync directions. Press, slide into a
gap, and release; also slide toward a neighboring button. Check that no unintended
action occurs. Read long translated messages to their end while actions remain
visible. Check QR placement, repeated dialog opening/closing with Wi-Fi active,
and physical readability under the intended lighting and viewing angle.

## Uniform row layout

Trickler controls and single-line labels use a shared 44-pixel height with
8-pixel horizontal and vertical gaps. Five main-screen rows occupy 252 pixels, fitting
below the 44-pixel tab bar with page margins. Profile navigation uses 88-pixel
Up/Down controls around the restored 75-pixel profile/action row, with a 5-pixel
inset around its Tune/Delete buttons; tuning uses four equal rows across a
404-pixel content area, with its mode selector placed at the panel's top inset
and Save/Close at the bottom inset. In Steps mode, one wide button cycles
through the `1`, `10`, and `100` increments beside the motor-test button,
directly below the step value. The profile-entry selector occupies the following
full-width row. Standalone labels add their centering
padding to an existing local style instead of allocating another style entry.
Multiline
messages and the Info log retain their variable/viewport heights. The native
harness checks exact row heights and gaps in addition to clipping and input.

Validation after row normalization: native geometry/input/lifecycle checks and
ESP32 compile-only build passed; SD JSON and whitespace checks passed.

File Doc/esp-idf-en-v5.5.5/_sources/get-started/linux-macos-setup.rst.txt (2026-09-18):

********************************************
Standard Toolchain Setup for Linux and macOS
********************************************

:link_to_translation:`zh_CN:[中文]`

Installation Step by Step
=========================

This is a detailed roadmap to walk you through the installation process.

Setting up Development Environment
~~~~~~~~~~~~~~~~~~~~~~~~~~~~~~~~~~

These are the steps for setting up the ESP-IDF for your {IDF_TARGET_NAME}.

* :ref:`get-started-prerequisites`
* :ref:`get-started-get-esp-idf`
* :ref:`get-started-set-up-tools`
* :ref:`get-started-set-up-env`
* :ref:`get-started-start-a-project`

.. _get-started-prerequisites:

Step 1. Install Prerequisites
=============================

In order to use ESP-IDF with the {IDF_TARGET_NAME}, you need to install some software packages based on your Operating System. This setup guide helps you on getting everything installed on Linux and macOS based systems.

For Linux Users
~~~~~~~~~~~~~~~

To compile using ESP-IDF, you need to get the following packages. The command to run depends on which distribution of Linux you are using:

- Ubuntu and Debian::

    sudo apt-get install git wget flex bison gperf python3 python3-pip python3-venv cmake ninja-build ccache libffi-dev libssl-dev dfu-util libusb-1.0-0

- CentOS 7 & 8::

    sudo yum -y update && sudo yum install git wget flex bison gperf python3 cmake ninja-build ccache dfu-util libusbx

CentOS 7 is still supported but CentOS version 8 is recommended for a better user experience.

- Arch::

    sudo pacman -S --needed gcc git make flex bison gperf python cmake ninja ccache dfu-util libusb python-pip

.. note::
    - CMake version 3.16 or newer is required for use with ESP-IDF. Run "tools/idf_tools.py install cmake" to install a suitable version if your OS versions does not have one.
    - If you do not see your Linux distribution in the above list then please check its documentation to find out which command to use for package installation.

For macOS Users
~~~~~~~~~~~~~~~

ESP-IDF uses the version of Python installed by default on macOS.

- Install CMake & Ninja build:

  - If you have HomeBrew_, you can run::

      brew install cmake ninja dfu-util

  - If you have MacPorts_, you can run::

      sudo port install cmake ninja dfu-util

  - Otherwise, consult the CMake_ and Ninja_ home pages for macOS installation downloads.

- It is strongly recommended to also install ccache_ for faster builds. If you have HomeBrew_, this can be done via ``brew install ccache`` or ``sudo port install ccache`` on MacPorts_.

.. note::
   If an error like this is shown during any step::

     xcrun: error: invalid active developer path (/Library/Developer/CommandLineTools), missing xcrun at: /Library/Developer/CommandLineTools/usr/bin/xcrun

   Then you need to install the XCode command line tools to continue. You can install these by running ``xcode-select --install``.

Apple M1 Users
~~~~~~~~~~~~~~

If you use Apple M1 platform and see an error like this::

      WARNING: directory for tool xtensa-esp32-elf version esp-2021r2-patch3-8.4.0 is present, but tool was not found
      ERROR: tool xtensa-esp32-elf has no installed versions. Please run 'install.sh' to install it.

or::

      zsh: bad CPU type in executable: ~/.espressif/tools/xtensa-esp32-elf/esp-2021r2-patch3-8.4.0/xtensa-esp32-elf/bin/xtensa-esp32-elf-gcc

Then you need to install Apple Rosetta 2 by running

.. code-block:: bash

    /usr/sbin/softwareupdate --install-rosetta --agree-to-license

Installing Python 3
~~~~~~~~~~~~~~~~~~~

Based on macOS `Catalina 10.15 release notes`_, use of Python 2.7 is not recommended and Python 2.7 is not included by default in future versions of macOS. Check what Python you currently have::

  python --version

If the output is like ``Python 2.7.17``, your default interpreter is Python 2.7. If so, also check if Python 3 is not already installed on your computer::

  python3 --version

If the above command returns an error, it means Python 3 is not installed.

Below is an overview of the steps to install Python 3.

  - Installing with HomeBrew_ can be done as follows::

      brew install python3

  - If you have MacPorts_, you can run::

      sudo port install python38

.. _get-started-get-esp-idf:

Step 2. Get ESP-IDF
===================

To build applications for the {IDF_TARGET_NAME}, you need the software libraries provided by Espressif in `ESP-IDF repository <https://github.com/espressif/esp-idf>`_.

To get ESP-IDF, navigate to your installation directory and clone the repository with ``git clone``, following instructions below specific to your operating system.

Open Terminal, and run the following commands:

.. include-build-file:: inc/git-clone-bash.inc

ESP-IDF is downloaded into ``~/esp/esp-idf``.

Consult :doc:`/versions` for information about which ESP-IDF version to use in a given situation.

.. _get-started-set-up-tools:

Step 3. Set up the Tools
========================

Aside from the ESP-IDF, you also need to install the tools used by ESP-IDF, such as the compiler, debugger, Python packages, etc, for projects supporting {IDF_TARGET_NAME}.

.. code-block:: bash

    cd ~/esp/esp-idf
    ./install.sh {IDF_TARGET_PATH_NAME}

or with Fish shell

.. code-block:: fish

    cd ~/esp/esp-idf
    ./install.fish {IDF_TARGET_PATH_NAME}

The above commands install tools for {IDF_TARGET_NAME} only. If you intend to develop projects for more chip targets then you should list all of them and run for example:

.. code-block:: bash

    cd ~/esp/esp-idf
    ./install.sh esp32,esp32s2

or with Fish shell

.. code-block:: fish

    cd ~/esp/esp-idf
    ./install.fish esp32,esp32s2

In order to install tools for all supported targets please run the following command:

.. code-block:: bash

    cd ~/esp/esp-idf
    ./install.sh all

or with Fish shell

.. code-block:: fish

    cd ~/esp/esp-idf
    ./install.fish all

.. note::
   For macOS users, if an error like this is shown during any step::

     <urlopen error [SSL: CERTIFICATE_VERIFY_FAILED] certificate verify failed: unable to get local issuer certificate (_ssl.c:xxx)

   You may run ``Install Certificates.command`` in the Python folder of your computer to install certificates. For details, see `Download Error While Installing ESP-IDF Tools <https://github.com/espressif/esp-idf/issues/4775>`_.

Alternative File Downloads
~~~~~~~~~~~~~~~~~~~~~~~~~~

The tools installer downloads a number of files attached to GitHub Releases. If accessing GitHub is slow then it is possible to set an environment variable to prefer Espressif's download server for GitHub asset downloads.

.. note:: This setting only controls individual tools downloaded from GitHub releases, it does not change the URLs used to access any Git repositories.

To prefer the Espressif download server when installing tools, use the following sequence of commands when running ``install.sh``:

.. code-block:: bash

    cd ~/esp/esp-idf
    export IDF_GITHUB_ASSETS="dl.espressif.com/github_assets"
    ./install.sh

.. note::
    For users in China, we recommend using our download server located in China for faster download speed.
    Alternatively, you can set as well the environment variable ``PIP_INDEX_URL`` to the China mirror of PyPI.

    .. code-block:: bash

        cd ~/esp/esp-idf
        export IDF_GITHUB_ASSETS="dl.espressif.cn/github_assets"
        export PIP_INDEX_URL="https://mirrors.tuna.tsinghua.edu.cn/pypi/web/simple"
        ./install.sh

Customizing the Tools Installation Path
~~~~~~~~~~~~~~~~~~~~~~~~~~~~~~~~~~~~~~~

The scripts introduced in this step install compilation tools required by ESP-IDF inside the user home directory: ``$HOME/.espressif`` on Linux. If you wish to install the tools into a different directory, **export the environment variable IDF_TOOLS_PATH before running the installation scripts**. Make sure that your user account has sufficient permissions to read and write this path.

.. code-block:: bash

    export IDF_TOOLS_PATH="$HOME/required_idf_tools_path"
    ./install.sh

    . ./export.sh

If changing the ``IDF_TOOLS_PATH``, make sure it is exported in the environment before running any ESP-IDF tools or scripts.

.. note::
    Using ``IDF_TOOLS_PATH`` in variable assignment, e.g., ``IDF_TOOLS_PATH="$HOME/required_idf_tools_path" ./install.sh``, without prior exporting, will not work in most shells because the variable assignment will not affect the current execution environment, even if it's exported/changed in the sourced script.

.. _get-started-set-up-env:

Step 4. Set up the Environment Variables
========================================

The installed tools are not yet added to the PATH environment variable. To make the tools usable from the command line, some environment variables must be set. ESP-IDF provides another script which does that.

In the terminal where you are going to use ESP-IDF, run:

.. code-block:: bash

    . $HOME/esp/esp-idf/export.sh

or for fish (supported only since fish version 3.0.0):

.. code-block:: bash

    . $HOME/esp/esp-idf/export.fish

Note the space between the leading dot and the path!

If you plan to use esp-idf frequently, you can create an alias for executing ``export.sh``:

1.  Copy and paste the following command to your shell's profile (``.profile``, ``.bashrc``, ``.zprofile``, etc.)

    .. code-block:: bash

        alias get_idf='. $HOME/esp/esp-idf/export.sh'

2.  Refresh the configuration by restarting the terminal session or by running ``source [path to profile]``, for example, ``source ~/.bashrc``.

Now you can run ``get_idf`` to set up or refresh the esp-idf environment in any terminal session.

Technically, you can add ``export.sh`` to your shell's profile directly; however, it is not recommended. Doing so activates IDF virtual environment in every terminal session (including those where IDF is not needed), defeating the purpose of the virtual environment and likely affecting other software.

.. _get-started-start-a-project:
.. _get-started-build:
.. _get-started-configure:
.. _get-started-connect:
.. _get-started-linux-macos-first-steps:

Step 5. First Steps on ESP-IDF
==============================

.. include:: linux-macos-start-project.rst
.. include:: start-project.rst

Tip: Updating ESP-IDF
======================

It is recommended to update ESP-IDF from time to time, as newer versions fix bugs and/or provide new features. Please note that each ESP-IDF major and minor release version has an associated support period, and when one release branch is approaching end of life (EOL), all users are encouraged to upgrade their projects to more recent ESP-IDF releases, to find out more about support periods, see :doc:`ESP-IDF Versions <../versions>`.

The simplest way to do the update is to delete the existing ``esp-idf`` folder and clone it again, as if performing the initial installation described in :ref:`get-started-get-esp-idf`.

Another solution is to update only what has changed. :ref:`The update procedure depends on the version of ESP-IDF you are using <updating>`.

After updating ESP-IDF, execute the Install script again, in case the new ESP-IDF version requires different versions of tools. See instructions at :ref:`get-started-set-up-tools`.

Once the new tools are installed, update the environment using the Export script. See instructions at :ref:`get-started-set-up-env`.

Related Documents
=================

    * :doc:`establish-serial-connection`
    * `Eclipse Plugin <https://github.com/espressif/idf-eclipse-plugin/blob/master/README.md>`_
    * `VSCode Extension <https://github.com/espressif/vscode-esp-idf-extension/blob/master/docs/tutorial/install.md>`_
    * :doc:`../api-guides/tools/idf-monitor`

.. toctree::
    :hidden:
    :maxdepth: 1

    establish-serial-connection
    flashing-troubleshooting

.. _AUR: https://wiki.archlinux.org/index.php/Arch_User_Repository
.. _First Steps on ESP-IDF: ../get-started/first-steps.html
.. _cmake: https://cmake.org/
.. _ninja: https://ninja-build.org/
.. _ccache: https://ccache.dev/
.. _homebrew: https://brew.sh/
.. _MacPorts: https://www.macports.org/install.php
.. _Catalina 10.15 release notes: https://developer.apple.com/documentation/macos-release-notes/macos-catalina-10_15-release-notes

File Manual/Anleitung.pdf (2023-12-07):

Version 2.00

# Erste Schritte

1. Verbinde die Steuereinheit mit der Waage via RS-232 Stecker
2. Verbinde die Steuereinheit mit dem Trickler
3. Stelle sicher das sich die SD-Karte in der Steuereinheit befindet
4. Verbinde die Steuereinheit mit dem Netzteil

Jetzt sollte der Robo-Trickler mit einem standard Pulverprofil starten.

Es MUSS für jedes Pulver ein eigenes Profil angelegt (https://github.com/ripper121/RoboTrickler/wiki#erstellen) werden, um ein optimales Trickeln zu gewährleiste!

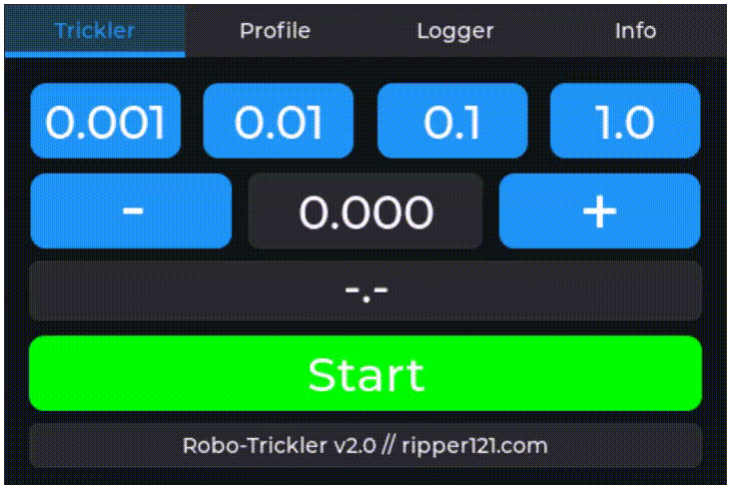
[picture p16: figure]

# SD Karte

Falls die SD-Karte mal defekt ist oder ihr beim bearbeiten ein Fehler gemacht habt, hier könnt ihr euch die SD-Karten Daten neu runterladen.

https://github.com/ripper121/RoboTrickler/releases

Die SD-Karte muss mit FAT32 formatiert sein!

Bei FAT32 gehen nur SD-Karten bis MAXIMAL 32GB!

Unter Windows könnt ihr auch die "Create_SD_Card.bat" benutzen. Dort gebt ihr einfach den Laufwerksbuchstaben ein und die SD-Karte wird automatisch erstellt.

Video Anleitung:

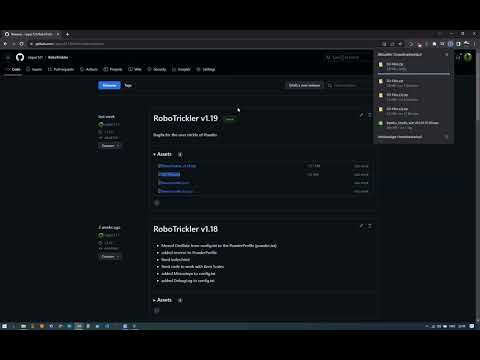
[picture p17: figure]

# Konfiguration

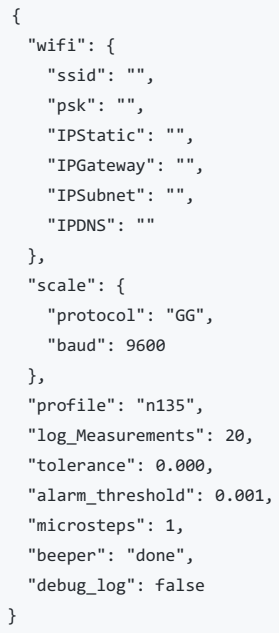
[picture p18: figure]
"wifi": {; "ssid": "",; "psk": "",; "IPStatic": "",; "IPGateway": "",; "IPSubnet": "",; "IPDNS": ""; "scale": {; "protocol": "GG",; "baud": 9600; "profile": "n135",; "log_Measurements": 20,; "tolerance": 0.000,; "alarm_threshold": 0.001,; "microsteps": 1,; "beeper": "done",; "debug_log": false

wifi
ssid <- Trage hier dein Wifi Name ein, nur 2.4GHz wird unterstützt!
psk <- Trage hier dein Wifi Password ein
IPStatic <- Optional Statische IP Adresse
IPGateway <- Wenn Statische IP Adresse verwendet wird muss die Gateway IP ausgefüllt werden. IPSubnet <- Wenn Statische IP Adresse verwendet wird muss die Subnet IP ausgefüllt werden.
IPDNS <- Optional DNS Server IP
scale
potocol <- zur Zeit werden G&G Waage "GG" , Satorius (Denver) Waagen "SBI", Kern "KERN", Steingerg "STE" und A&D "AD" unterstützt. baud <- die Geschwindigkeit mit der die Waage Daten per RS-232 überträgt, meistens mit 9600 baud
profile <- der Name des Pulverprofils, wenn der Dateiname "MeinPulver.txt" ist, muss hier "MeinPulver" eingetragen werden
log_measurements <- Wie viele Messungen im "Logger Modus" durchgeführt werden müssen, damit der Wert in die CSV Datei geschrieben wird tolerance <- Ist die Abweichung die erlaubt ist zum Zielgewicht in %
alarm_threshold <- Gibt ein alarm aus wenn der Zielwert um % überschritten ist
beep <- Es gibt 3 Modies, 1. Wenn der Trickler fertig ist soll es Piepen ("done"), 2. Beim drücken auf den Touchscreen ("button"), 3. Beides ("both") microsteps <- Microsteps Einstellung vom Schrittmotor 1/1 = 1, 1/2 = 2, ... , 1/64 = 64
debug_log <- true loggt die Daten der Wagge in eine debugLog.txt auf der SD-Karte. Default false

Auf der SD-Karte ist die configGenerator.html welche das erstellen einer Konfiguration erleichtert. Der configGenerator wird auch via Webserver bereitgestellt.

Wenn die Konfiguration fertig ist, kopiert den Text in eure config.txt oder geht auf Download und kopiert die config.txt direkt auf die SD-Karte

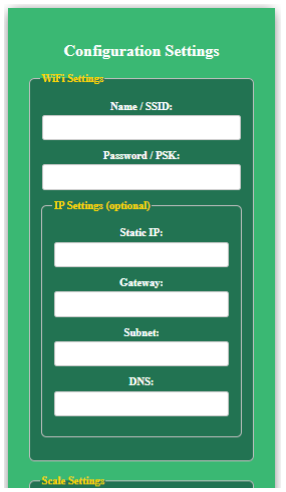
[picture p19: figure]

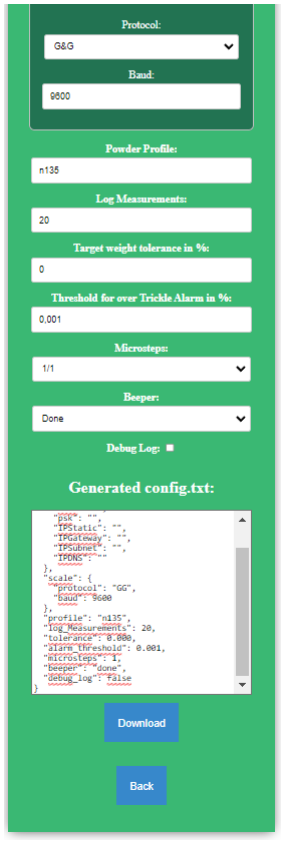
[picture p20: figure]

# Pulverprofil

### Aufbau

Beispiel N135 Pulverprofil mit 10 Schritten:

{
"1": {
"weight": 1,
"steps": 4091,
"speed": 200,
"measurements": 5,
"oscillate": false,
"reverse": false
},
"2": {
"weight": 0.5,
"steps": 2045,
"speed": 200,
"measurements": 5,
"oscillate": false,
"reverse": false

},
"3": {
"weight": 0.25,
"steps": 1023,
"speed": 200,
"measurements": 5,
"oscillate": false,
"reverse": false
},
"4": {
"weight": 0.125,
"steps": 511,
"speed": 200,
"measurements": 5,
"oscillate": false,
"reverse": false
},
"5": {
"weight": 0.063,
"steps": 258,
"speed": 200,
"measurements": 5,
"oscillate": false,
"reverse": false
},
"6": {
"weight": 0.031,
"steps": 127,
"speed": 200,
"measurements": 5,
"oscillate": false,
"reverse": false
},
"7": {
"weight": 0.016,
"steps": 65,
"speed": 200,
"measurements": 5,
"oscillate": false,
"reverse": false
},
"8": {
"weight": 0.008,
"steps": 33,
"speed": 200,
"measurements": 5,
"oscillate": false,
"reverse": false
},
"9": {
"weight": 0.004,
"steps": 16,
"speed": 200,
"measurements": 20,
"oscillate": false,
"reverse": false
},
"10": {
"weight": 0,
"steps": 15,
"speed": 200,
"measurements": 20,
"oscillate": false,
"reverse": false
}
}

}

"ZAHL" <- Nummer des Schrittes, es sind 1 bis 32 Schritte möglich, muss aufsteigend nummeriert sein number <- welcher Trickler verwendet werden soll, 1 oder 2, Default ist 1 wenn man den Parameter weg lässt weight <- das Gewicht bei dem dieser Schritt ausgeführt wird
steps <- Schritte die der Trickler ausführen soll (360 = 1 Umdrehung)
speed <- Geschwindigkeit mit dem der Trickler sich dreht
measurements <- Messungen die durchgeführt werden müssen bis zum nächsten Trickel
oscillate <- für Tricklerrohre die innen nicht blank sind auf "false" stellen (rohr dreht sich in eine Richtung), default ist "true" dabei bewegt sich das rohr hin und her (180°)
reverse <- true = Drehrichtung umkehren, default ist false

### Erstellen

Zum erstellen eines eigenen Pulverprofils wird das "calibrate" Profil benutzt, welches sich in der calibrate.txt befindet

calibrate.txt

{
"1":{
"weight":0.001,
"steps":3600,
"speed":200,
"measurements":20,
"oscillate":false
}
}

Das "calibrate" Profil dreht den Trickler 10x mit der Geschwindigkeit von 200.

Um das "calibrate" Profil zu benutzen, wählen wir dieses im "Profile Tab" mit den Pfeiltasten aus.

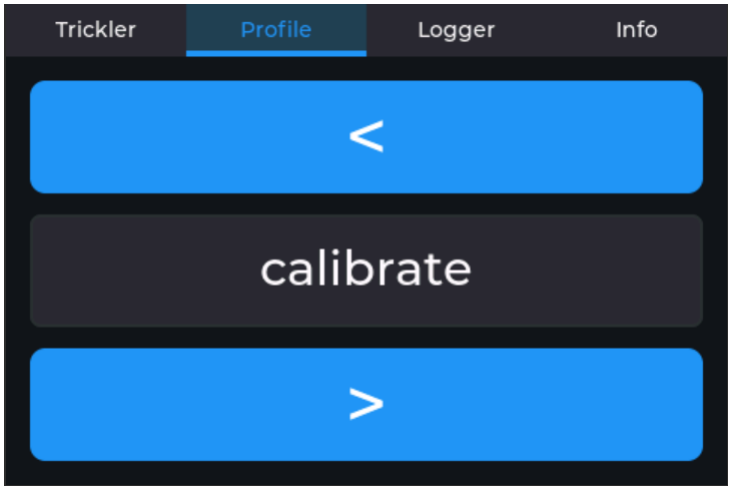
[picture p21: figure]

1. wenn das erfolgt ist stellt beim Gewicht was getrickelt werden soll >3 Gramm ein
2. jetzt drückt auf Start
3. wenn ihr den Trickler Tank erst frisch mit Pulver aufgefüllt habt, lasst den Trickler mindestens 5x laufen, damit das Trickler rohr richtig gefüllt ist
4. notiert euch wie viel der Trickler bei einem Durchgang (10 Umdrehungen) getrickelt hat (ihr könnt auch den Durchschnitt von 10 Trickelvorgängen benutzen, dann wird es noch genauer)
5. öffnet die profileGenerator.html von der SD Karte (oder im Webbrowser wenn der Trickler mit Wifi verbunden ist)

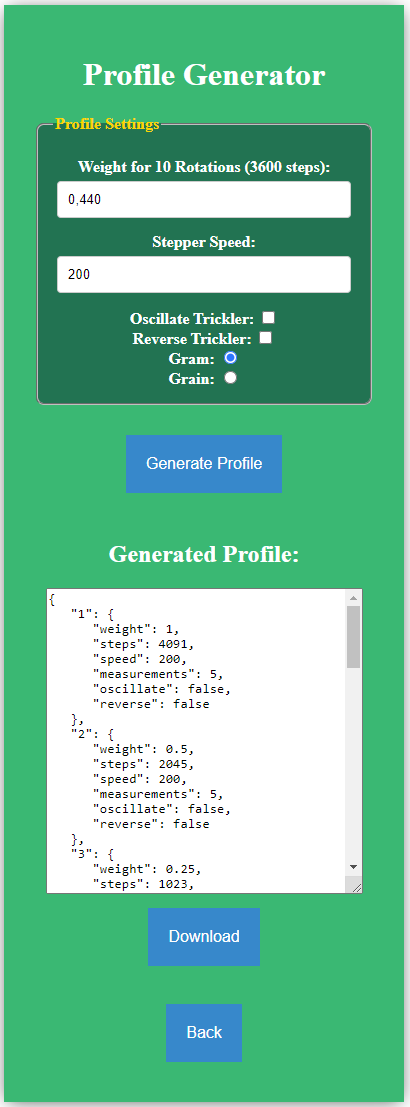
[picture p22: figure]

6. tragt auf der profileGenerator.html den notierten Wert bei "Weight for 3600 steps:" ein
7. falls ihr die calibrate.txt Geschwindigkeit angepasst habt, tragt diese bei "Stepper Speed:" ein
8. klicke auf "Generate Profile"
9. es wird ein neues Pulverprofil erzeugt
10. Klickt auf Download und bennent die MyPowderName.txt in euer Pulver um
11. Steckt die SD-Karte wieder in den Trickler, jetzt sollte euer neues Profil im "Profile Tab" auswählbar sein

Ihr könnt natürlich auch das Pulverprofil komplett selbst erstellen. Der Generator erzeugt nur eine Basis auf die man aufbauen kann.

Noch ein paar Dinge auf die man achten sollte.

Wenn man zu wenig "steps" angibt (kommt auf den Motor an der im Trickler verbaut ist) dann kann es sein der Trickler bewegt sich gar nicht.

Der "speed" sollte sich zwischen 10 und 200 befinden, sonst kann es wieder ein das der Trickler sich nicht bewegt.

Niedrigere trickel Geschwindigkeiten ("speed") bringen meist eine Höhere Pulvermenge getrickelt.

Es kann in einem Profil bei jedem Schritt eine andere Geschwindigkeit benutzt werden. z.B. kann man am Anfang eine langsame Geschwindigkeit benutzen um viel Pulver zu fördern und am ende hohe Geschwindigkeit um nur ein Körnchen zu trickeln

Zu viele "measurements" und es kann sehr lange dauern bis ein Schritt bearbeitet ist. Gerade bei den anfangs Schritten kann man mit 2 Messungen gut fahren. Gegen ende sollte man aber min. 5 Messungen durchführen lassen.

### Gramm / Grain

Wenn ihr die Einheit eurer Waage umstellt, muss auch das Pulverprofil angepasst werden.

Hierzu müsst ihr bei jedem Schritt im Profil die "weight" auf Grain oder Gramm umrechnen / umstellen.

Wenn ihr bereits ein Profil in Gramm habt, dann einfach die Gramm mit 15,432 multiplizieren.

Ihr könnt auch für jedes Pulver jeweils für Gramm und Grain ein eigenes Profil (https://github.com/ripper121/RoboTrickler/wiki#pulverprofil) anlegen.

Z.B. RS14Gramm.txt und RS14Grain.txt

diese könnt ihr dann einfach in der config.txt (https://github.com/ripper121/RoboTrickler/wiki#konfiguration) bei "powder" umstellen.

Gramm Profil:

{
"1":{
"weight":0.001,
"steps":3600,
"speed":200,
"measurements":20
}
}

Umgebaut auf Grain:

{
"1":{
"weight":0.015,
"steps":3600,
"speed":200,
"measurements":20
}
}

### Mehrere Trickler

Über den Parameter "number" im Pulverprofil legt man fest welcher Trickler benutzt wird.

Wird "number" nicht angegeben benutzt er standardmäßig Trickler 1, um kompatibel mit den alten Profilen zu bleiben.

Statt ein 2. Trickler kann man hier auch ein Pulverfüllgerät mit einem Schrittmotor versehen und diesen im Profil genau so benutzen (hier kann die option "oscillate" hilfreich sein).

Pulverprofil beispiel für 2 Trickler, in den Schritten 1-5 benutzt er Trickler 2 und in den restlichen Trickler 1:

{
"1": {
"number": 2,
"weight": 1,
"steps": 2000,
"speed": 200,
"measurements": 2
},
"2": {
"number": 2,
"weight": 0.5,
"steps": 1000,
"speed": 200,
"measurements": 2
},
"3": {
"number": 2,

"number": 2,
"weight": 0.25,
"steps": 500,
"speed": 200,
"measurements": 2
},
"4": {
"number": 2,
"weight": 0.125,
"steps": 250,
"speed": 200,
"measurements": 2
},
"5": {
"number": 2,
"weight": 0.062,
"steps": 124,
"speed": 200,
"measurements": 2
},
"6": {
"number": 1,
"weight": 0.031,
"steps": 62,
"speed": 200,
"measurements": 2
},
"7": {
"number": 1,
"weight": 0.015,
"steps": 30,
"speed": 200,
"measurements": 2
},
"8": {
"number": 1,
"weight": 0.007,
"steps": 14,
"speed": 200,
"measurements": 5
},
"9": {
"number": 1,
"weight": 0.003,
"steps": 6,
"speed": 200,
"measurements": 15
},
"10": {
"number": 1,
"weight": 0.001,
"steps": 5,
"speed": 200,
"measurements": 20
}
}

# Firmware Update

Es gibt 2 Möglichkeiten ein Firmware Update zu machen.

1. Ihr kopiert eine update.bin in auf die SD-Karte
2. Ihr macht das Update via Webbrowser -> "FW Update"

Die neuste Firmware findet ihr hier: https://github.com/ripper121/RoboTrickler/releases

# Deserialization failed

Prüfe die config.txt und das damit verwendete Pulverprofil mit dieser Seite: https://jsonformatter.curiousconcept.com

Die Seite zeigt Formatierungsfehler in den Dateien an und korrigiert sie ggf.

# Logger

Drückt auf den "Logger Tab" um in den Logger Modus zu gehen

1. Klicke auf Start und platziere dein erste Objekt z.B. ein Projektil
2. Warte bis "Count: N Saved" auf dem Display steht
3. nehme das Projektil von der Waage und platziere es auf Position 1 in einem Brett
4. warte bis "Place next..." auf dem Display steht
5. platziere das nächste Projektil auf der Waage usw...
6. wenn du alle Projektile gewogen hast klicke auf Stop
7. öffne die Logdatei auf der SD-Karte, sie befindet sich in dem Ordner "log"
8. die Logdatei ist im CSV format abgespeichert, dies kann man mit jedem Tabellenkalkulationsprogramm öffnen z.B. Excel
9. Mit Excel (oder anderer Software) kann man sich jetzt die Projektile nach Gewicht sortieren

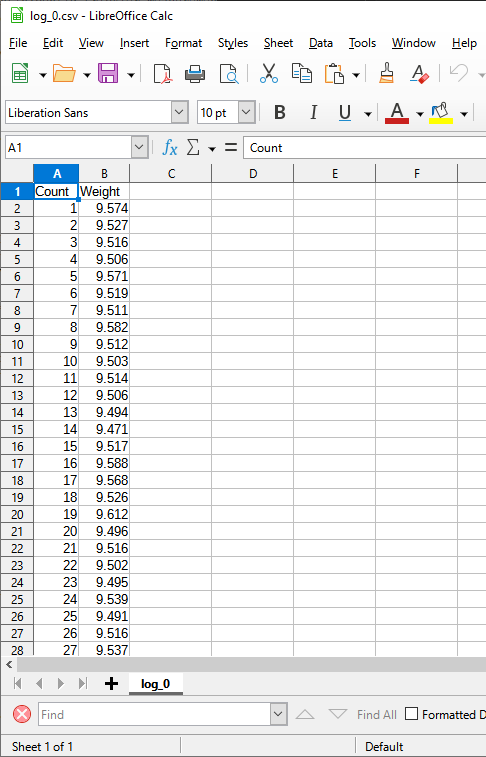
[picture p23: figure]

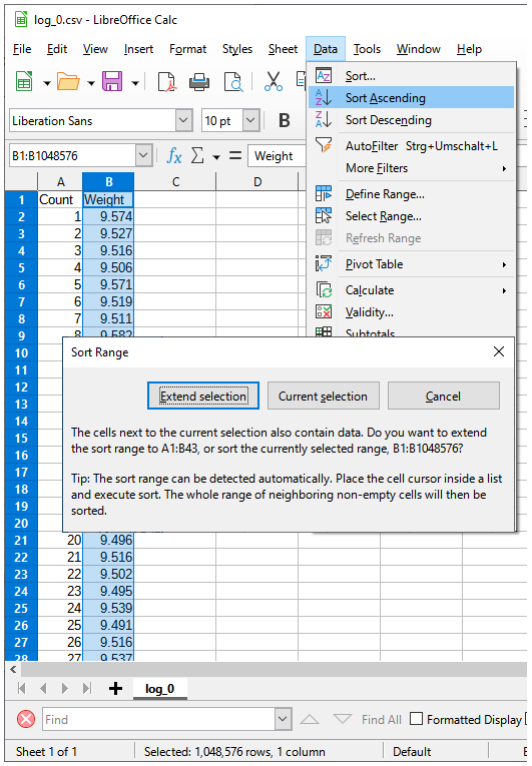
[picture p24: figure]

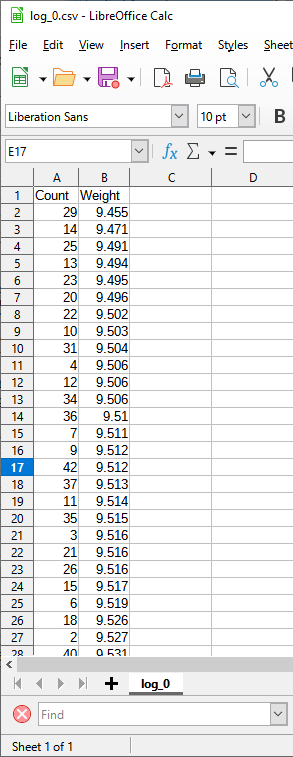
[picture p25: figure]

Video Anleitung:

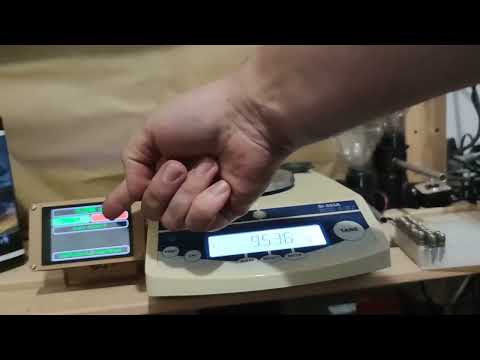
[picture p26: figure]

# Wifi (Wlan)

Um den Wifi Modus zu Aktivieren trage SSID (Wifi Name) und PSK (Wifi Password) in die "config.txt" ein. !!! nur 2.4GHz Wifi wird unterstützt !!!

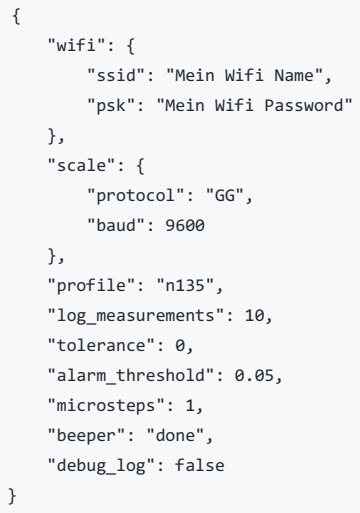
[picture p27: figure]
"wifi": {; "ssid": "Mein Wifi Name",; "psk": "Mein Wifi Password"; "scale": {; "protocol": "GG",; "baud": 9600; "profile": "n135",; "log_measurements": 10,; "tolerance": 0,; "alarm_threshold": 0.05,; "microsteps": 1,; "beeper": "done",; "debug_log": false

Der Trickler sollte sich dann beim Starten mit dem WIFI verbinden und dies im Display anzeigen "Connecting WIFI...". Bei Erfolgreicher Verbindung steht auch im "Info Tab" die IP-Adresse worüber der Trickler erreichbar ist.

Je nachdem welchen Router Ihr habt, solltet ihr den Trickler jetzt über http://robo-trickler.local oder http://robo-trickler erreichen. Wenn das nicht geht, benutzt die IP-Adresse welche im "Info Tab" erscheint und gebt diese IP dann im Browser ein, z.B. http://192.168.178.22

!!! die Website vom Trickler funktioniert nur wenn er nicht Läuft, also klickt vorher nochmal auf "Stop" !!!

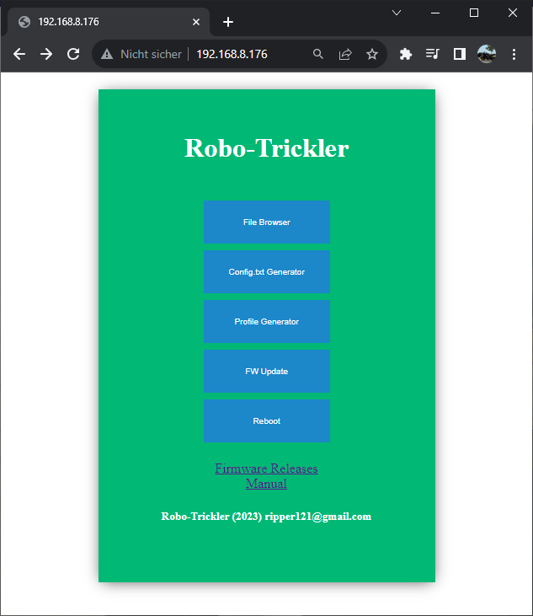
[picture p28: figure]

# File Browser

Mit dem File Browser könnt ihr die Dateien auf der SD-Karte ganz bequem über den Webbrowser bearbeiten, ohne jedes mal die SD-Karte raus nehmen zu müssen.

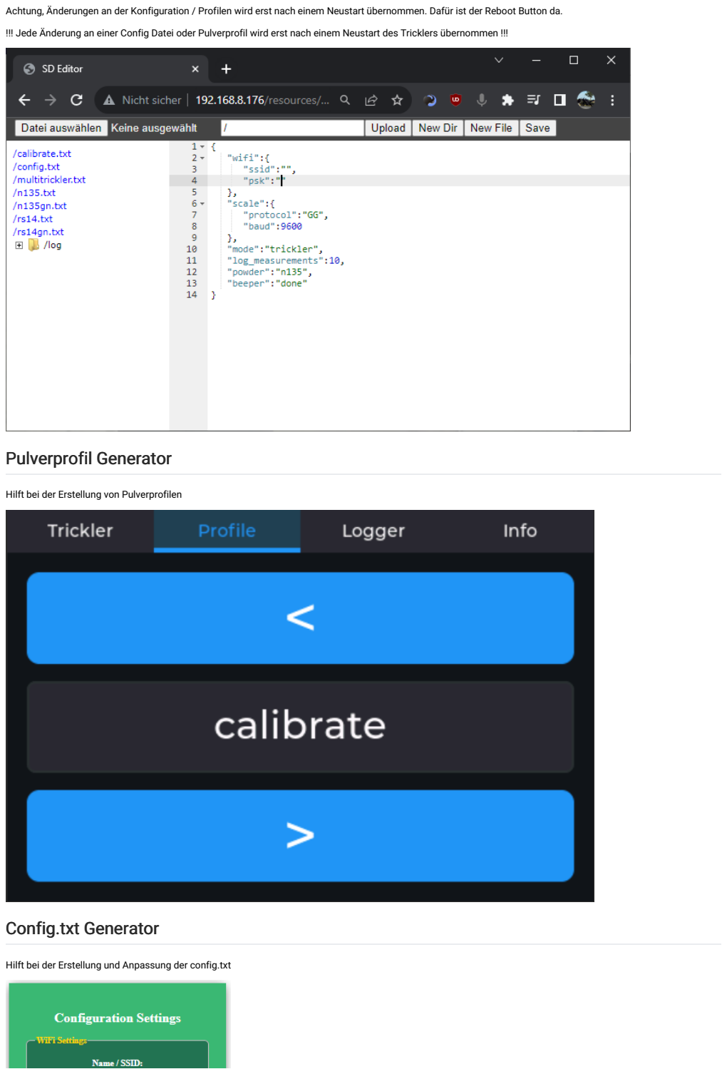
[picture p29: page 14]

Achtung, Änderungen an der Konfiguration / Profilen wird erst nach einem Neustart übernommen. Dafür ist der Reboot Button da.

!!! Jede Änderung an einer Config Datei oder Pulverprofil wird erst nach einem Neustart des Tricklers übernommen !!!

# Pulverprofil Generator

Hilft bei der Erstellung von Pulverprofilen

# Config.txt Generator

Hilft bei der Erstellung und Anpassung der config.txt

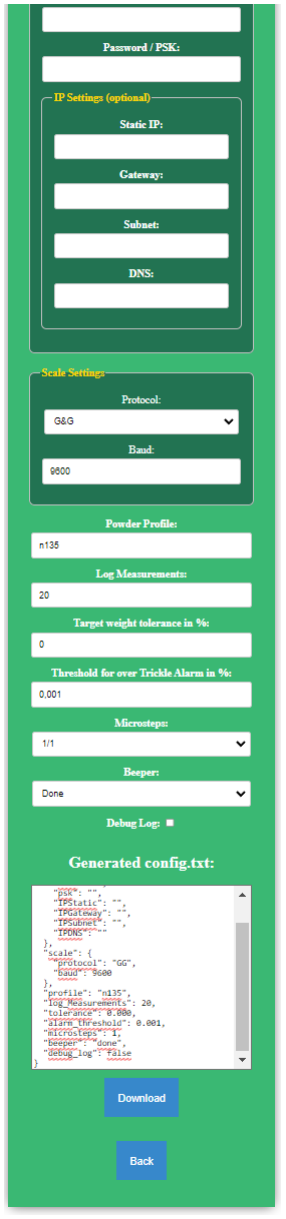
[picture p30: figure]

# Zielgewicht

Um das Zielgewicht zu setzen kann man http://robo-trickler.local/setValue?targetWeight=WERT aufrufen. Also für 2.353g -> http://robo-trickler.local/setValue?

targetWeight=2.353

# Reboot

Um den Trickler neu zu Starten könnt Ihr auf "Reboot" Klicken im Webbrowser

# Firmware Update

Es gibt 2 Möglichkeiten ein Firmware Update zu machen.

1. Ihr kopiert eine update.bin in auf die SD-Karte
2. Ihr macht das Update via Webbrowser -> "FW Update"

Die neuste Firmware findet ihr hier: https://github.com/ripper121/RoboTrickler/releases

# Waagen

G&G

Es sollten alle G&G Waagen mit RS232 kompatibel sein.

Hier auch eine Empfehlung für Wiederlader direkt von G&G: https://gandg.de/download/anleitungen/Wiederlader%20Infobrosch%C3%BCre.pdf

### Einstellungen

Man sollte alle Filter aus machen und die Sensibilität auf Maximal stellen.

Falls der Gewichtswert zu sehr schwanken sollte, spielt etwas mit C1 und C2.

Anleitung für G&G Waagen: https://gandg.de/index.php/downloads

Beispiel Einstellung für die PLC100:

C1 - 0 Sensibilität
C2 - 0 Schwingungsfilter
C3 - 6 Baudrate (9600)
C4 - 27 Gerätenummer
C5 - 0 Autom. Abschaltung
C6 - 0 Belegung der Print-Taste C7 - 0 Hinteres Display abschalten

### Gender Changer Adapter

Es wird ein RS232 Gender Changer Adapter benötigt:

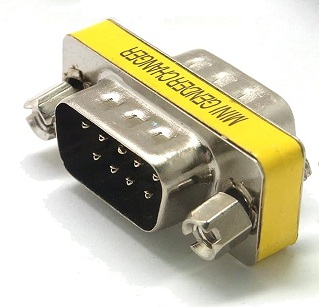
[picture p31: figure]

Und ein RS232-TTL Converter mit Female Anschluss:

### PLC Serie

Empfehlung die G&G PLC100BC, max. 100g und 0,001g Messbereich reichen aus. Diese habe ich selbst im Einsatz.

https://waage-shop.com/PLC-Feinwaagen-Tischwaage-Praezisionswaagen_10https://www.amazon.de/PLC-Baureihe-Pr%C3%A4zisionswaage-Industriewaage-Tischwaage-Batteriebetrie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

### JJ-B Serie

Empfehlung die G&G JJ100B, max. 100g und 0,001g Messbereich reichen aus. Die G&G JJ200B wurde auch schon getestet.

https://waage-shop.com/JJ-B-Praezisionwaage-Laborwaagehttps://www.amazon.de/JJ100B-Pr%C3%A4zisionswaage-Laborwaage-Industriewaage-Tischwaage/dp/B004S5V09I

### JJ-BC

Wer es ganz genau haben will kann diese Serie bentuzen.

0,1 mg Messbereich.

https://waage-shop.com/JJ-BC-Industrie-Analysenwaage-mit-externer-Justierung-120g-01mg-JJ124BChttps://www.amazon.de/Industrie-Analysenwaage-Pr%C3%A4zisionwaage-Feinw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

# Sartorius

Es sollten alle Sartorius Waagen mit RS232 kompatibel sein.

Ich habe das Übertragungsprotokoll Sartorius Balance Interface (SBI) implementiert

SI-603A habe ich persönlich (sehr altes model, wurde noch von Denver vertrieben)

Ihr braucht ein RS232-TTL Converter mit Male Anschluss:

### Einstellungen

DAT.PROT. - SBI

BAUD - 9600

PARITY - NONE

HANDSHK. - NONE

DATABIT - 8 BITS

KOM. AUSG. - AUTO.OHN

ABBRUCH - AUS

AUTO.ZYK - JEDER

FORMAT - 16 ZEICH.

AUTO.TARA - AUS

DEZ.ZEICH. - DEZ.PUNKT

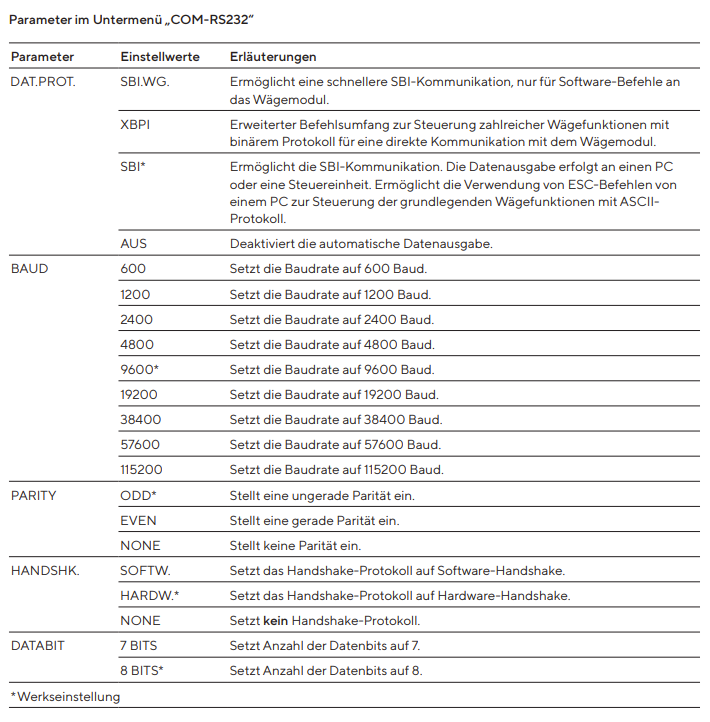
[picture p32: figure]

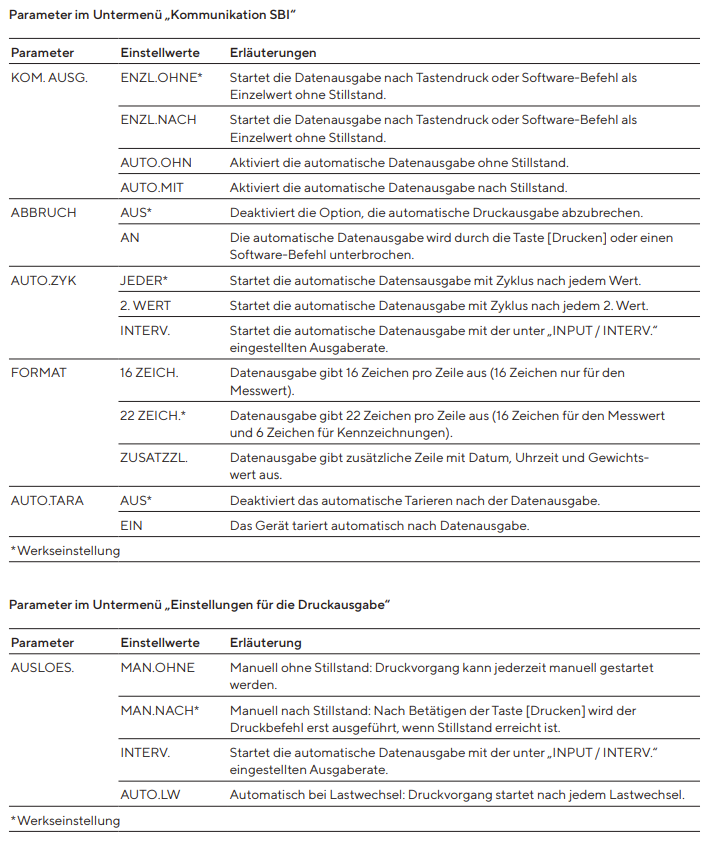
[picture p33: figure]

https://www.sartorius.com/download/492950/manual-cubis-mce-precision-balances-wmc6024-d-data.pdf

# Kern

### Einstellungen

Die Einstellungen sind für die Kern 440-21a sollten aber auf die anderen Modelle auch zutreffen.

Kern 440-21a wurde erfolgreich getestet.

Betriebsanleitung Kern 440 (https://dok.kern-sohn.com/manuals/files/German/440-BA-d-1643.pdf)

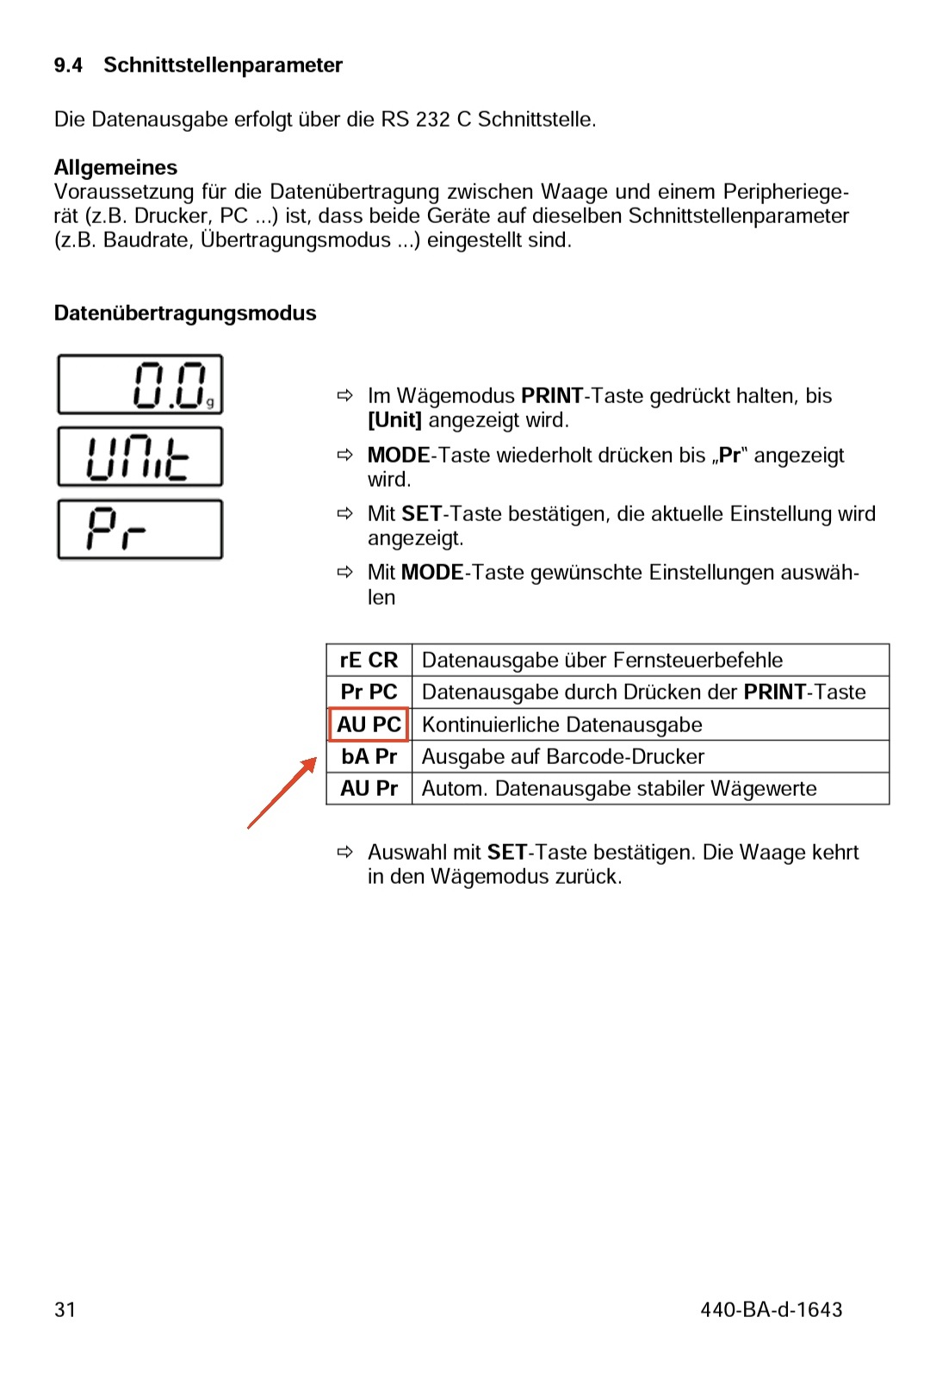
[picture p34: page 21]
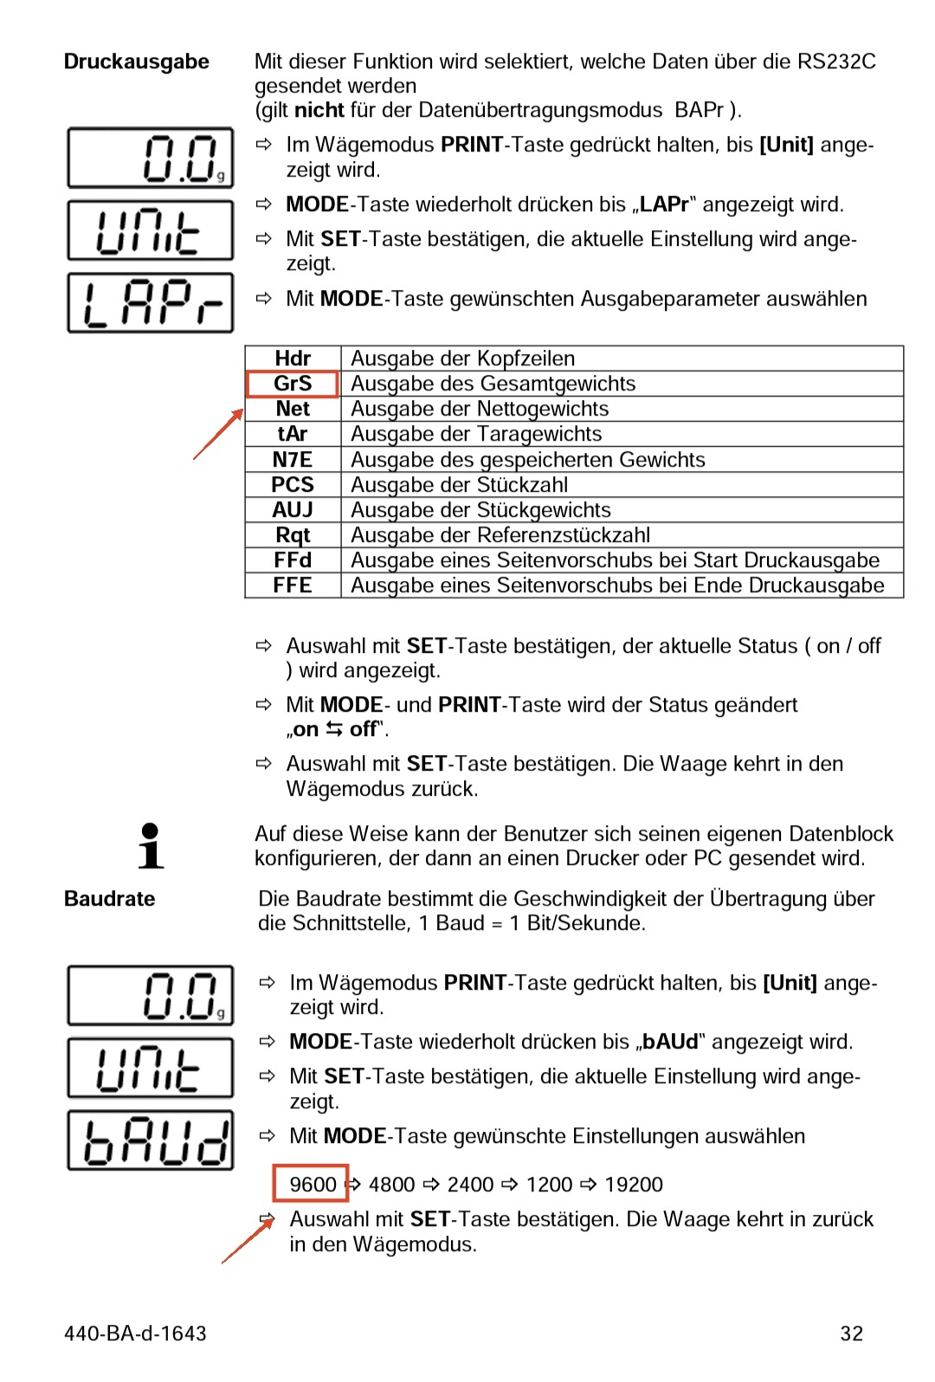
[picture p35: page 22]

Ihr braucht ein RS232-TTL Converter mit Male Anschluss:

A&D

Sind Implementiert aber noch nicht getestet

# Steinberg

SBS-LW-200A

2COM
9600 brt

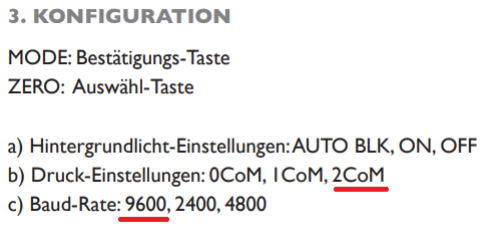
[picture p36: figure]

Ihr braucht ein RS232-TTL Converter mit Male Anschluss:

# Flash via USB

Lade die ZIP runter : https://github.com/ripper121/RoboTrickler/releases/latest

Entpacke sie und öffnet die flash.bat und tragt den COM Port ein, dann drückt auf Enter.

Im Geräte-Manager wird dir der Com-Port angezeigt (in meinem Fall, COM7).

Video Anleitung:

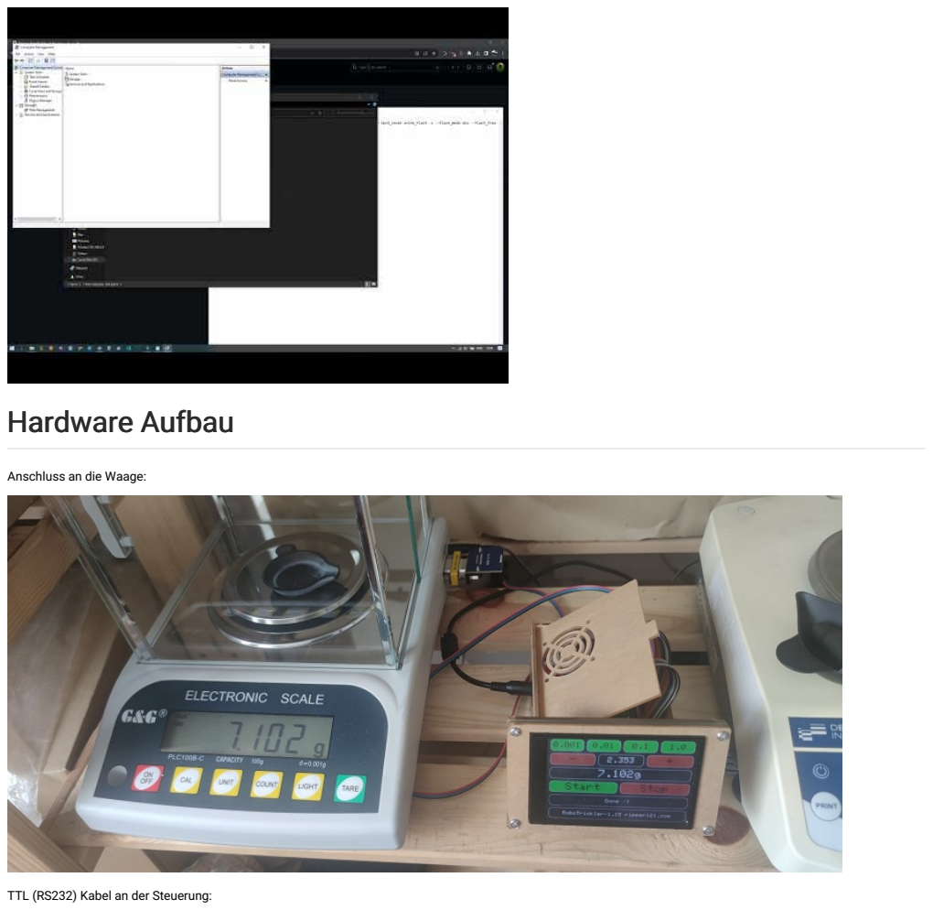
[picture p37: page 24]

# Hardware Aufbau

Anschluss an die Waage:

TTL (RS232) Kabel an der Steuerung:

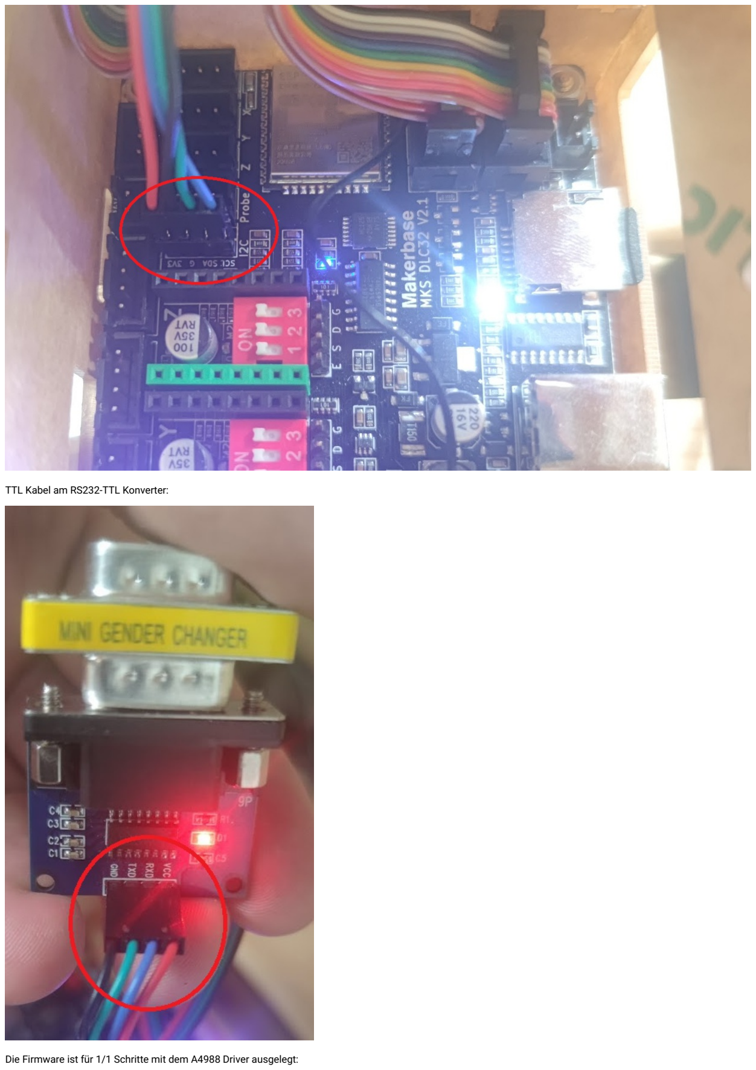
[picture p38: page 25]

TTL Kabel am RS232-TTL Konverter:

Die Firmware ist für 1/1 Schritte mit dem A4988 Driver ausgelegt:

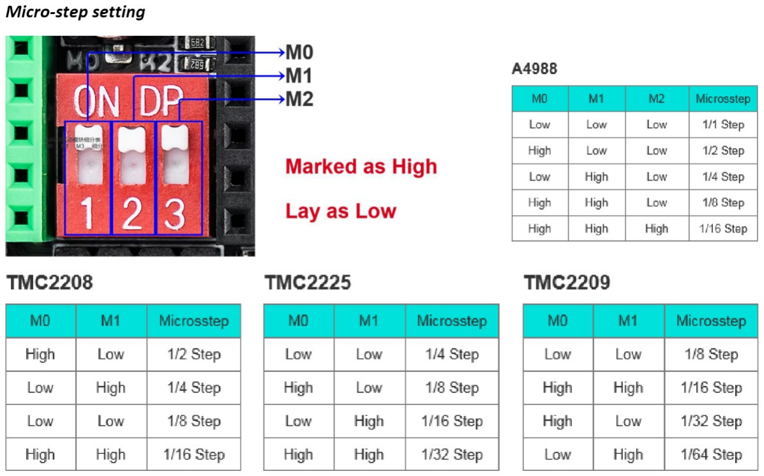
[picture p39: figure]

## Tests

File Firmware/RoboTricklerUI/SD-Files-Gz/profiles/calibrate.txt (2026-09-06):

{
    "measurements": 10,
    "stepper": {
        "id": 1,
        "revolutions": 100,
        "rpm": 200,
        "reverse": false
    }
}

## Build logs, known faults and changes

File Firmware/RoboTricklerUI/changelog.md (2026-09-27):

# Changelog

## 2.15 (pre-release)

### Firmware-Update

Es gibt zwei Möglichkeiten, die Firmware über USB zu installieren:

1. **Webbrowser:** Öffne den [Web-Updater](https://ripper121.github.io/RoboTrickler/), wähle eine Version aus und folge den Anweisungen auf dem Bildschirm.
2. **USB-Paket:** Lade `USB-Flash.zip` von der [Release-Seite](https://github.com/ripper121/RoboTrickler/releases/latest) herunter und entpacke es. Starte unter Windows `flash.bat`. Unter macOS oder Linux findest du die Anleitung zum Flashen im [Wiki](https://github.com/ripper121/RoboTrickler/wiki).

Formatiere nach der gewählten Methode die SD-Karte als FAT32. Entpacke die zur Firmware passende `SD-Files.zip` und kopiere ihren Inhalt direkt in das Hauptverzeichnis der SD-Karte.

Bei Fehlern oder Fragen: [Kontakt](https://shop.strenuous.dev/contact).

---

### Firmware update

Choose one of two ways to install the firmware over USB:

1. **Web browser:** Open the [browser updater](https://ripper121.github.io/RoboTrickler/), select a release, and follow the on-screen instructions.
2. **USB package:** Download `USB-Flash.zip` from the [releases page](https://github.com/ripper121/RoboTrickler/releases/latest) and extract it. On Windows, run `flash.bat`; on macOS or Linux, follow the [wiki's USB flashing instructions](https://github.com/ripper121/RoboTrickler/wiki).

After either method, format the SD card as FAT32. Extract the matching `SD-Files.zip` and copy its contents to the root of the SD card.

For errors or questions, [contact us](https://shop.strenuous.dev/contact).

---

### Highlights

- Larger, consistently spaced touchscreen controls, release-to-activate behavior, and cancellation when sliding off a button.
- One shared profile-tuning dialog for weight per revolution, map-limit factor, measurement counts, and step counts, including a motor test before saving.
- Compact profiles with defaults for optional fields, plus a configurable `general.trickleMapLimitFactor`.
- Complete USB installation from the browser using the 8 MB firmware/LittleFS layout.
- Optional 180-degree rotation of both the display and touchscreen, configurable from the web settings page.
- Redesigned browser file editor with a clearer desktop-style layout, status feedback, and improved file navigation.
- More robust file replacement, update validation, motor-error handling, and coordination between touchscreen, web, and trickler tasks.
- Updated German manual with current API methods and screenshots in `docs/screenshots/`.

### Added

- On-device tuning of `general.trickleMapLimitFactor` from `0.010` to `1.000`, with a default of `0.650`. Changing the factor or weight per revolution recalculates Stepper 1 map entries; step counts explicitly edited in the same tuning session take precedence.
- Factor support in generated profiles, the web profile editor, translations, and profile-creation tools; bundled compact `min` profile.
- Step-tuning motor test using the selected entry's motor, speed and direction with the unsaved step count. The test runs outside the LVGL callback, disables repeat activation while active, and is cancelled when the dialog closes.
- `trickle` in `GET /getTricklerState`: `0` for inactive operation, `1` for running/waiting, and `2` for finished while waiting for the charge to be removed. `running` remains true in states `1` and `2`.
- Browser USB installer at [ripper121.github.io/RoboTrickler](https://ripper121.github.io/RoboTrickler/) with release selection and English/German SD-card instructions. Its build verifies consistency of release images; a GitHub Pages workflow refreshes the available releases.
- `tools/tools.py` as a common launcher for firmware, release, filesystem, manual, and profile tools.
- Native LVGL layout verification and reproducible manual screenshots, including a local web preview with illustrative device responses.
- Optional `display.rotate180` configuration. When enabled, the firmware applies the matching display orientation and touch calibration at startup. Existing configurations without the new `display` object remain valid and default to the normal orientation.

### Changed

- Trickler and tuning controls use 44-pixel touch targets and 8-pixel spacing. Profile navigation buttons are 88 pixels high, with a larger central profile/action row.
- The tuning-mode selector is at the top, Save/Close stay at the bottom, and Step tuning places the `1`/`10`/`100` increment selector beside the blue motor-test triangle directly below the step count. The map-entry selector is on the next row.
- Save uses a green disk icon and Cancel a red cross. Confirmation dialogs use action symbols for OK, create, copy and delete; long text scrolls above fixed buttons. Compact Flash/SD icons open confirmations that spell out the copy direction.
- During operation, touchscreen target-weight controls are replaced by a full-width display of the live remaining delta (`targetWeight − scale weight`) and the calculated weight of the next bulk or fine trickle; disabled tab captions are hidden. The web interface disables profile selection while running; target/profile API mutations are rejected during a run.
- Normal profiles require `general.targetWeight`, Stepper 1 `weightPerRev`, and each map entry's `diffWeight`, `measurements`, and `stepper.steps`. Supported omitted fields receive defaults; unknown fields remain invalid. The web profile editor accepts this compact schema too.
- Automatically created profile filenames range from `powder_1.txt` to `powder_32.txt`; the total limit is still 32 valid profiles, including `calibrate`.
- **API migration:** `/setTarget`, `/setProfile`, `/system/start`, `/system/stop`, and `/reboot` now require **POST**. Read endpoints remain GET. Invalid target/profile arguments return `400`, and conflicting operations return `409`. Browser mutations validate the request origin; non-browser clients may omit `Origin`.
- File-editor paths and upload sizes are checked. Uploads and filesystem synchronization stage replacements through temporary files and backups. Firmware and LittleFS updates check image sizes against their partitions; firmware version checks bound the response size and reject malformed versions.
- Translation parsing retains only the required JSON section. Shared dialogs, directly rendered button symbols and fewer style allocations reduce memory use within the unchanged 24 KiB LVGL pool.
- Release tooling now builds only the 8 MB layout with LittleFS; the legacy 4 MB build option and legacy SD package are removed. Production builds clean stale build/staging output before rebuilding.
- Updated trickler CAD models and RS232 board design files.
- The browser file editor now uses a compact dark desktop-style interface with a title bar, current-file indicator, toolbar, Explorer sidebar, status bar, cursor position, localized operation states, and clearer upload controls. Loading a file also updates the upload target path, and text files open without retaining stale undo history.
- The bundled web home page now identifies firmware 2.15.

### Fixed

- Invalid `config.txt` is preserved as `config.cor.txt` before defaults are written; an older recovery copy is replaced. Corrupt profile recovery likewise replaces the matching `.cor.txt` consistently on SD and LittleFS.
- Interrupted configuration/profile replacements can recover their backups when filesystems are mounted. Failed file writes no longer report a successful upload.
- Synchronized runtime state, weight snapshots and dialog flags reduce conflicting operations and duplicate completion handling across tasks.
- Failed or partial I2S writes latch a motor-output fault and reject further moves until restart. Initialization now checks task, mutex and I2S setup failures; motor timing validation rejects unsupported step-rate combinations.
- Step-tuning tests interrupt the idle scale-poll wait so a missing scale response does not delay the requested test.
- File-editor create, delete, and directory-list requests now send named, URL-encoded path parameters that match the firmware handlers, preventing HTTP 500 errors for these operations and supporting special characters safely.

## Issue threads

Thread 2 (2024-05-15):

G&G scale configuration translation

eamars, 2024-05-15:
I just translated the G&G scale configuration from the manual written in Chinese. Hope this will help you too.

 | Variable | Name                                    | Recommended Value                        | All Options                                                                                                                                                    |
| -------- | --------------------------------------- | ---------------------------------------- | -------------------------------------------------------------------------------------------------------------------------------------------------------------- |
 | C1       | Sensitivity                             | 1                                        | 0 (highest)<br>1<br>2<br>3<br>4<br>5 (lowest, default)                                                                                                         |
 | C2       | Averaging Window (filter)               | 1                                        | 0 (shortest)<br>1<br>2<br>3<br>4 (longest, default)                                                                                                            |
| C3       | Serial Settings                         | 6                                        | 0 (9600 baud, stream mode)<br>1 (9600 baud, auto print on stable)<br>2 (600 baud, default)<br>3 (1200 baud)<br>4 (2400 baud)<br>5 (4800 baud)<br>6 (9600 baud) |
| C4       | Serial Comm Identification              | 33 (press COUNT to loop through options) | 27 (default)                                                                                                                                                   |
| C5       | Backlight                               | 0                                        | 0 (always on, default)<br>1 (auto)<br>2 (off)                                                                                                                  |
| C6       | Calibration | 0                                        | 0 (enable internal calibration)<br>1 (disable internal calibration)<br>2 (disable default internal calibration)                                                |

BTW I think C3 should be set to 0 and C4 to kept at 27.

ripper121, 2024-05-15:
0 (9600 baud, stream mode)
1 (9600 baud, auto print on stable)

Cool thats new to me. I updated the Wiki

C4 is not relevant for the Robo-Trickler. Im searching for the Decimal Dot, so i can get the Integers and decimal places part.
That works for almos any Scale Protocol so far.

```
...
    int separator = String(buff).indexOf('.');

    int N10P3 = 0;
    int N10P2 = 0;
    int N10P1 = 0;
    int N10N1 = 0;
    int N10N2 = 0;
    int N10N3 = 0;

    if (separator != -1)
    {
      N10P3 = (buff[separator - 3] > 0x30) ? (buff[separator - 3] - 0x30) : 0;
      N10P2 = (buff[separator - 2] > 0x30) ? (buff[separator - 2] - 0x30) : 0;
      N10P1 = (buff[separator - 1] > 0x30) ? (buff[separator - 1] - 0x30) : 0;
      N10N1 = (buff[separator + 1] > 0x30) ? (buff[separator + 1] - 0x30) : 0;
      N10N2 = (buff[separator + 2] > 0x30) ? (buff[separator + 2] - 0x30) : 0;
      N10N3 = (buff[separator + 3] > 0x30) ? (buff[separator + 3] - 0x30) : 0;

      weight = N10P3 * 100.0;
      weight += N10P2 * 10.0;
      weight += N10P1 * 1.0;
      weight += (N10N1 == 0) ? (0.0) : (N10N1 / 10.0);
      weight += (N10N2 == 0) ? (0.0) : (N10N2 / 100.0);
      weight += (N10N3 == 0) ? (0.0) : (N10N3 / 1000.0);
...
```

ripper121, 2024-05-15:
Ok thank you for your Help and these Infos :)
Can I close this?

eamars, 2024-05-15:
Yes sure.

Regarding the decoder, you might be able to use `strtof` to convert the decimal string into the floating point number. That could save you some lines of code.

ripper121, 2024-05-15:
Not sure if it is a good idea to use strtof in an µC enviroment, I feel saver right now with how I have done it :)

Closed 2024-05-15.

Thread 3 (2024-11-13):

radwag

marwaw-ops, 2024-11-13:
Hi,
Any plans to add roadwag scale ?
https://radwag.com/js/pdf_js/web/viewer.html?file=https://radwag.com/pdf2/de/CBCP-01-User-Manual-DE.pdf

ripper121, 2024-11-13:
Is there an auto print option?

If yes turn it on and give it a try.

marwaw-ops, 2025-01-13:
The Radwag WTC 2000scale works without a problem, (after setting 5.1.PC/5.1.2.Cnt CntA - continuous transmission)

ripper121, 2025-01-13:
You can also Try:

  "scale": {
    "protocol": "CUSTOM",
    "customCode": "SI",
    "baud": 9600
  }

This will send out a "SI CR LF" with a speed of 9600 BAUD (4.7.Ergebnis in der Grundeinheit sofort angeben)

marwaw-ops, 2025-01-18:
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

[Waga_Mw.3mf.zip](https://github.com/user-attachments/files/18464899/Waga_Mw.3mf.zip)

I printed another casing, with a movable display. If you think it's interesting, add it to the repository

ripper121, 2025-01-22:
Very Cool :)

Could you please also provide the original design files for this?

3mf, Stl or any other Mesh Based File is not good to work on for others.

So If someone else likes to modifiy it, it would be nice to have CAD files (original Project files).
STEP / STP would also good.

marwaw-ops, 2025-01-27:
Hi,
I attach the file in step format.

[Obudowa_wagi.step.zip](https://github.com/user-attachments/files/18558637/Obudowa_wagi.step.zip)

ripper121, 2025-01-27:
Thank you, added it: https://github.com/ripper121/RoboTrickler/commit/7eb23a1f9f37aec33a2078dbfed6bbf4231a5b5c

Closed 2025-01-27.

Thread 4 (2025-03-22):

Part list

hail0, 2025-03-22:
Hi everyone,

is there a part or buying list for the components (electronics, screws, aluminum tube, RS connector, etc.)
or did I read over it?

BR hail0

ripper121, 2025-03-22:
There you go: https://github.com/ripper121/RoboTrickler/blob/main/BOM.xlsx

hail0, 2025-03-22:
@ripper121: Omg i´m blind...Thx

Closed 2025-03-22.

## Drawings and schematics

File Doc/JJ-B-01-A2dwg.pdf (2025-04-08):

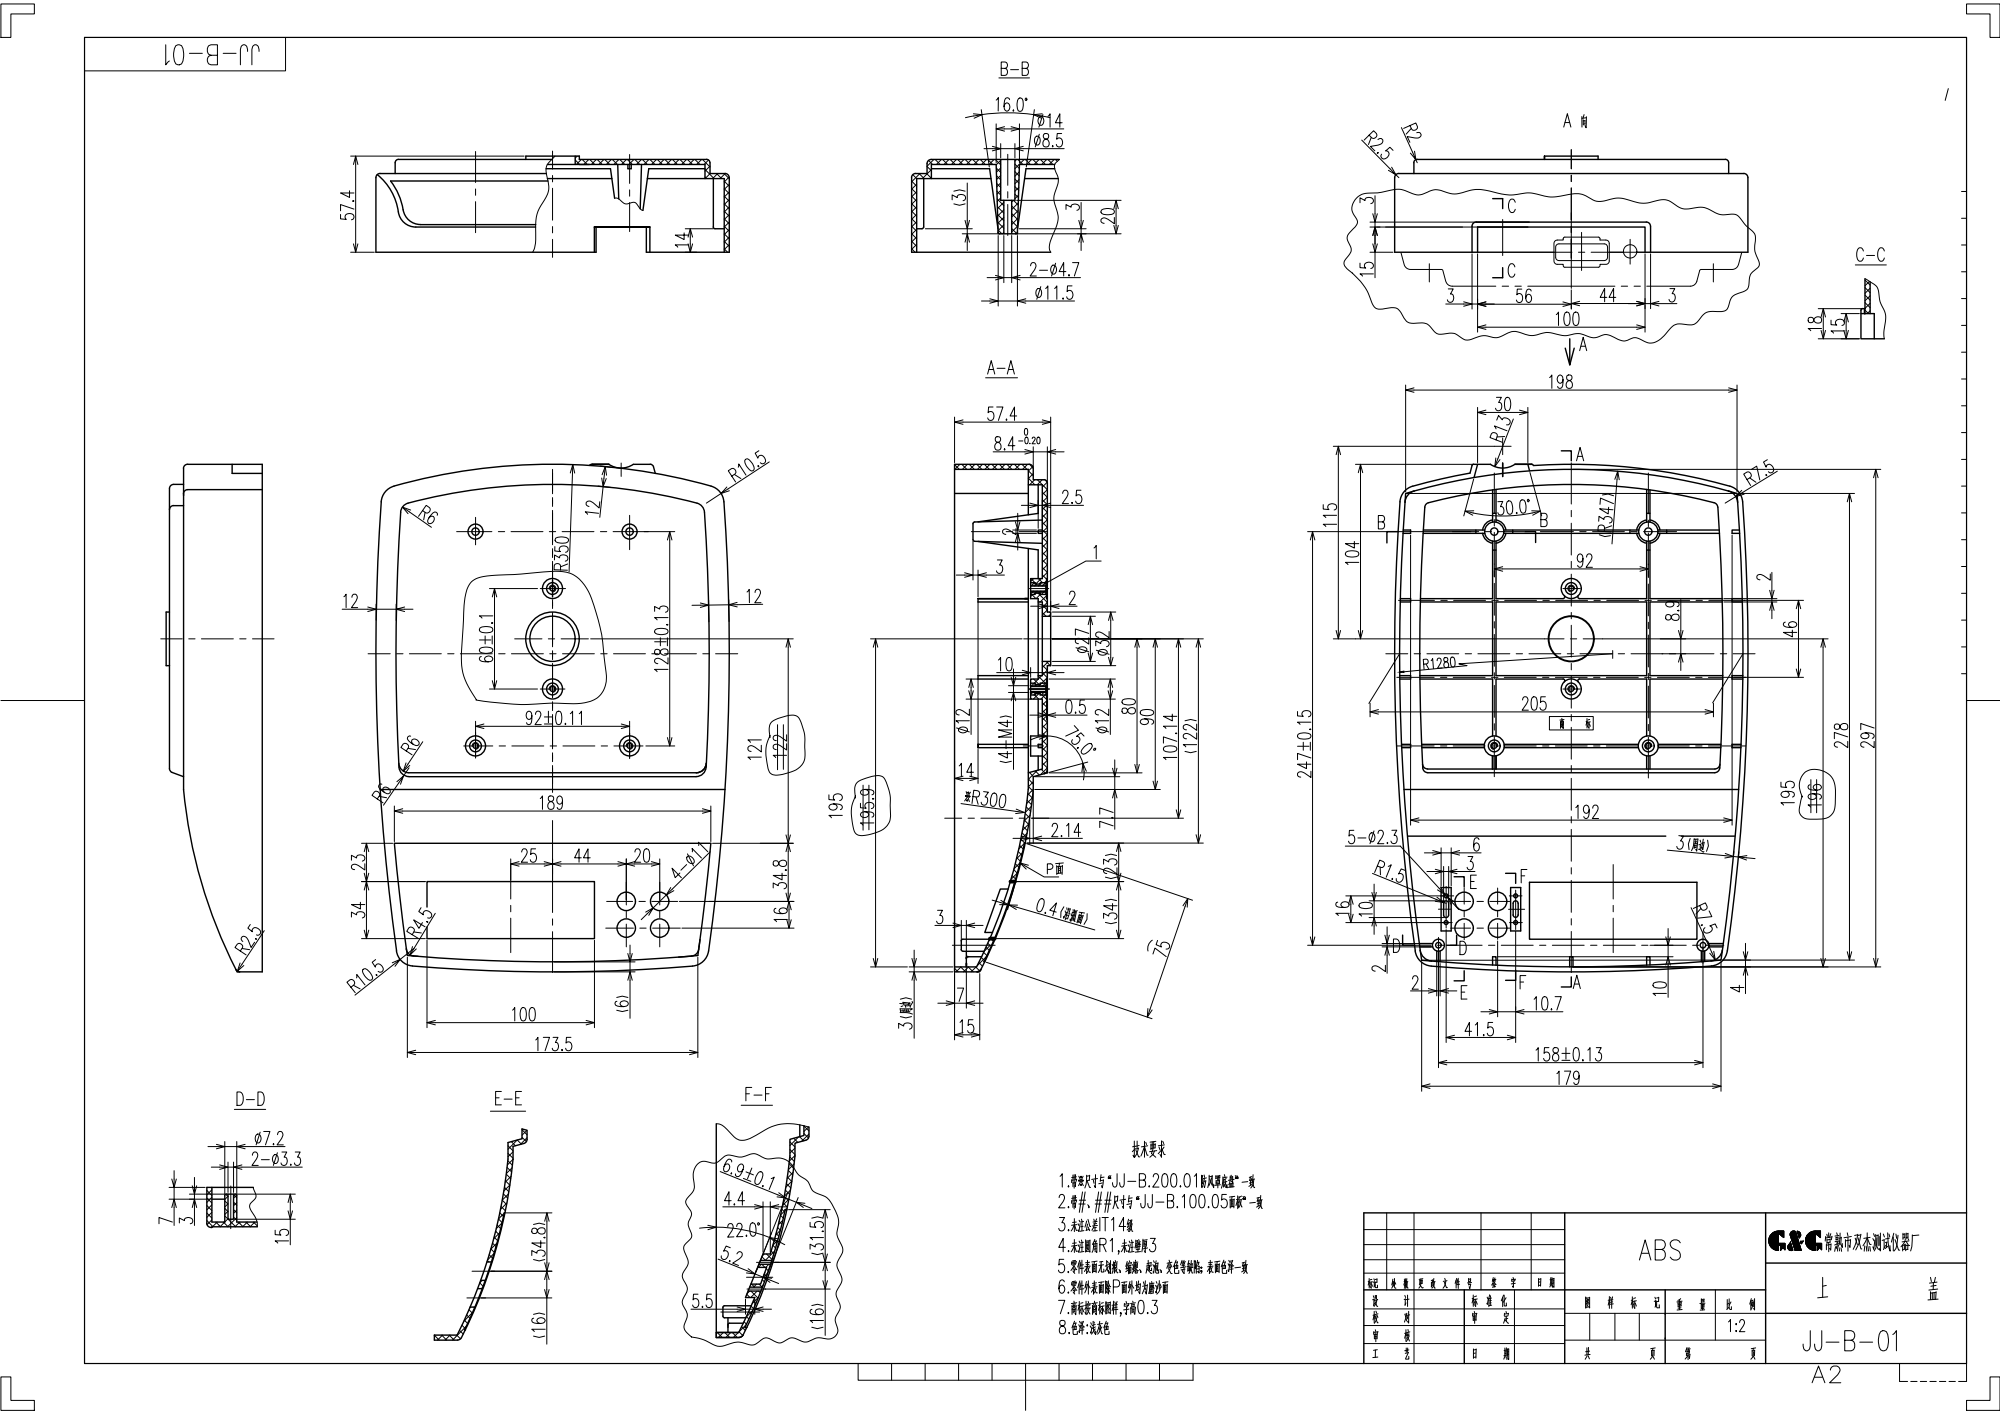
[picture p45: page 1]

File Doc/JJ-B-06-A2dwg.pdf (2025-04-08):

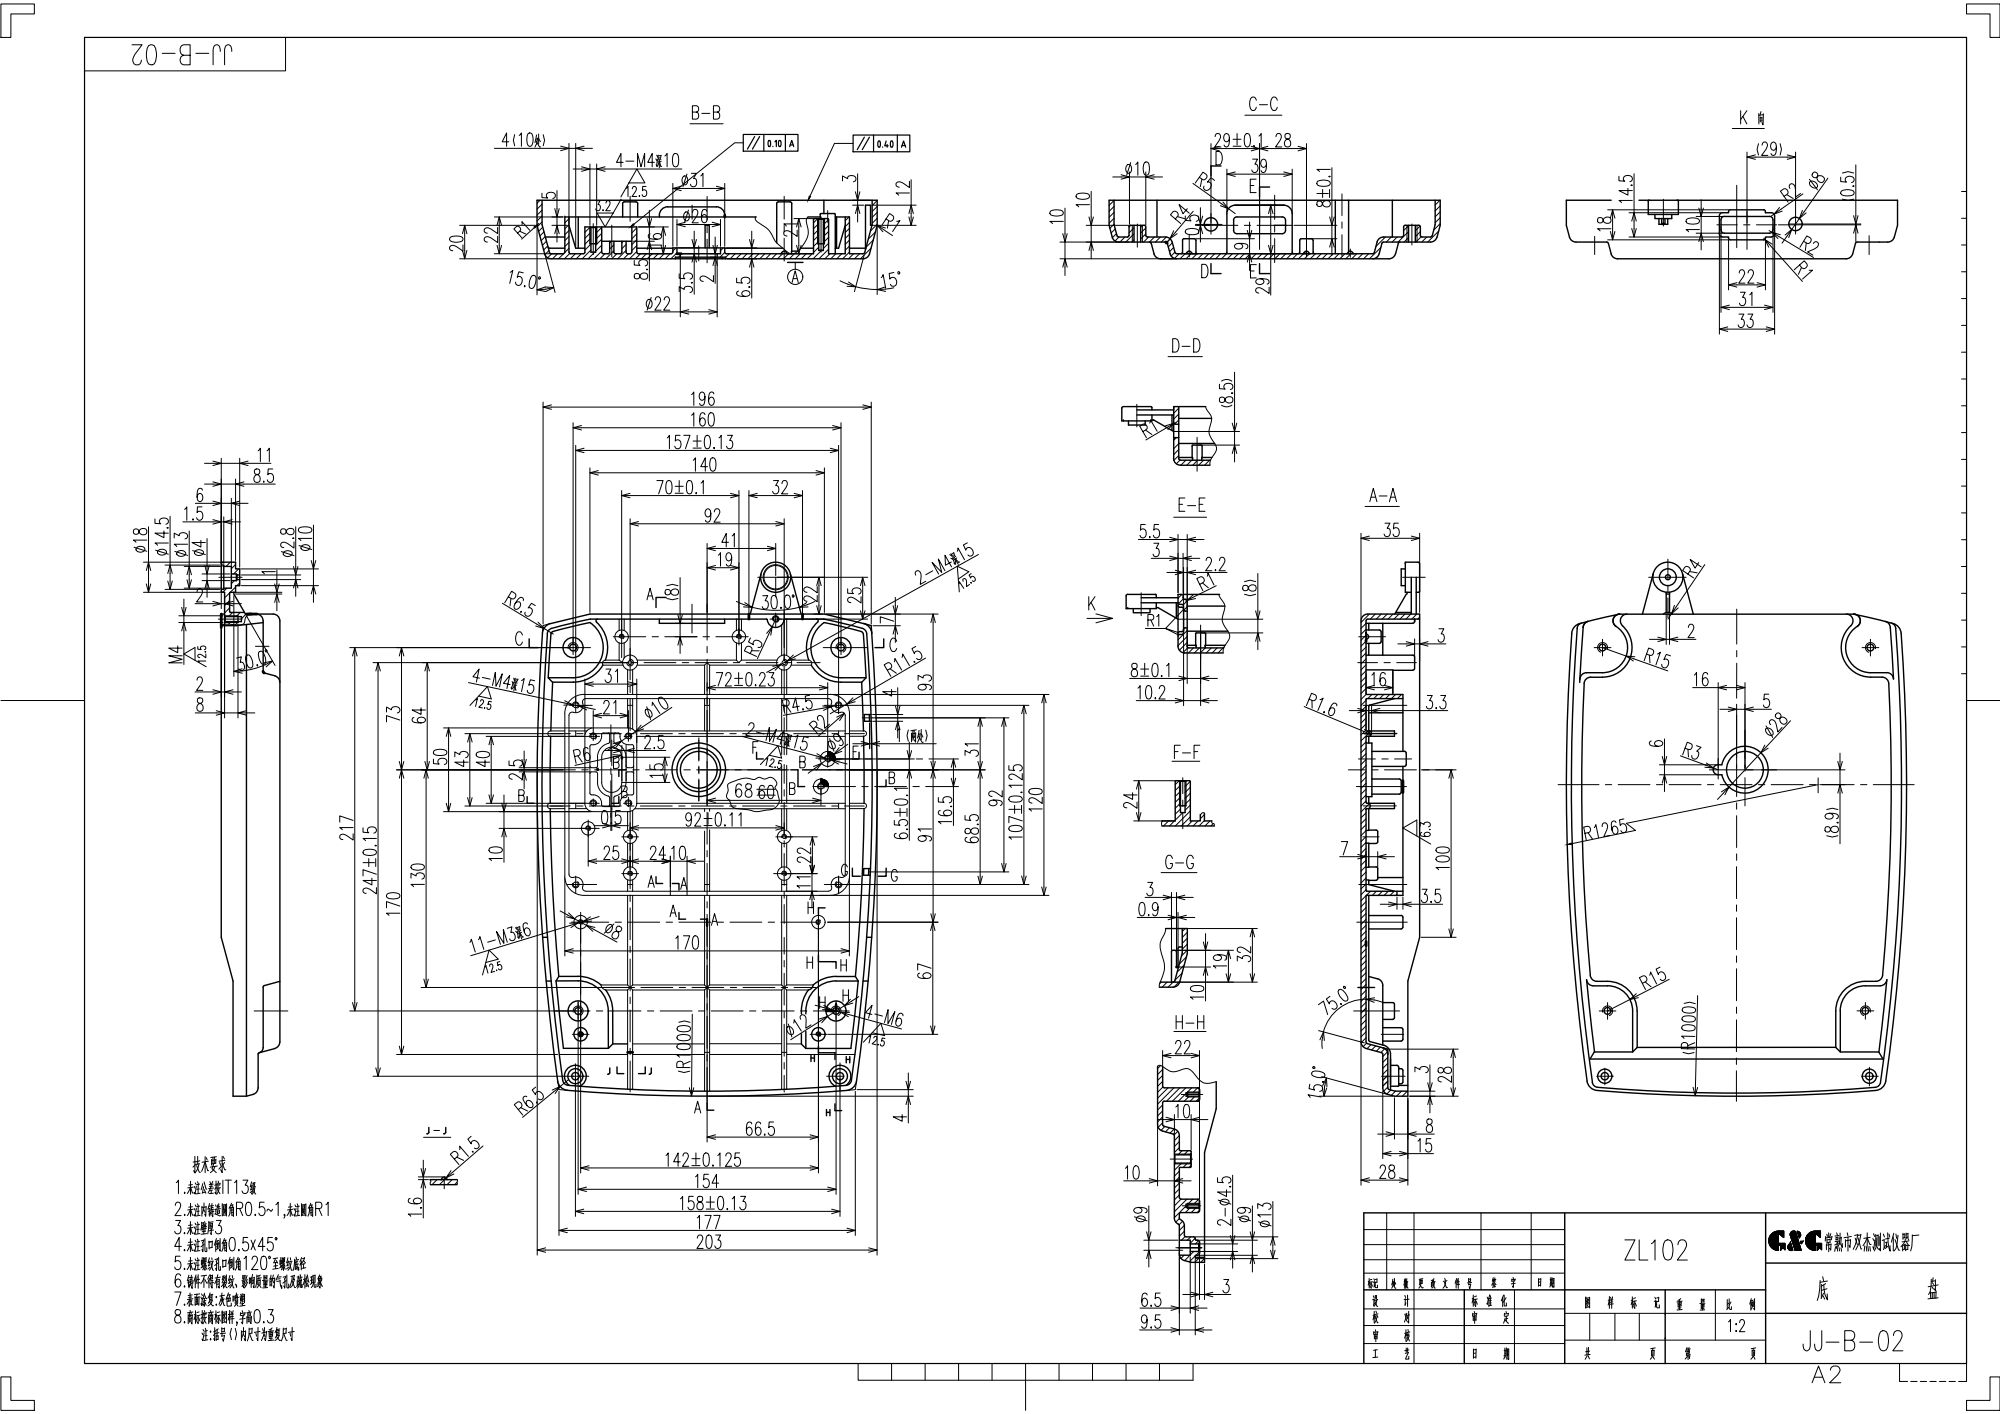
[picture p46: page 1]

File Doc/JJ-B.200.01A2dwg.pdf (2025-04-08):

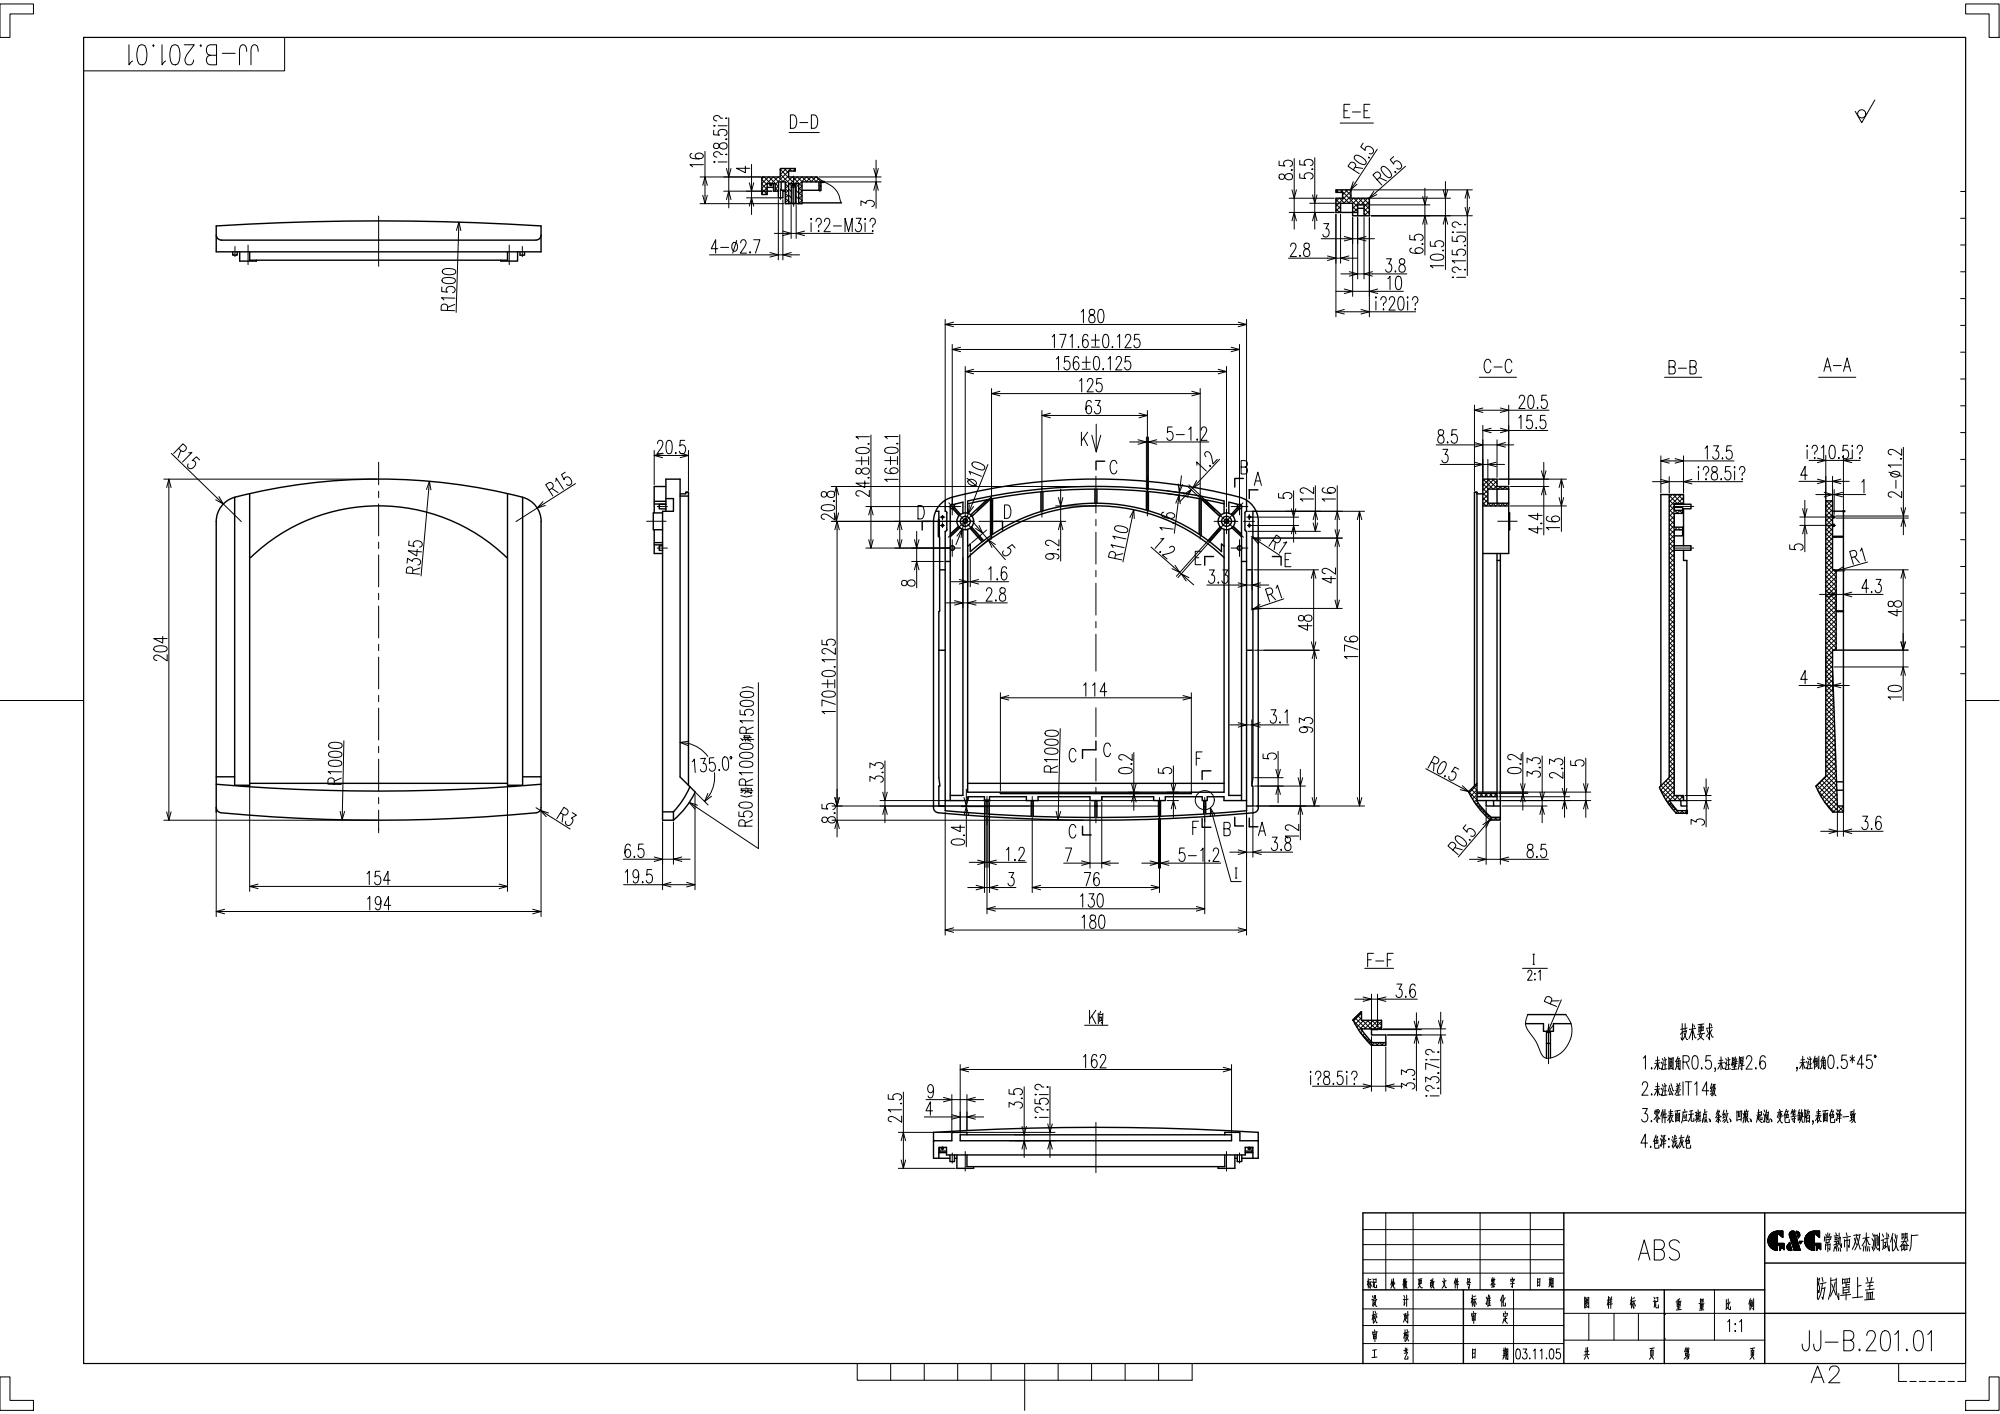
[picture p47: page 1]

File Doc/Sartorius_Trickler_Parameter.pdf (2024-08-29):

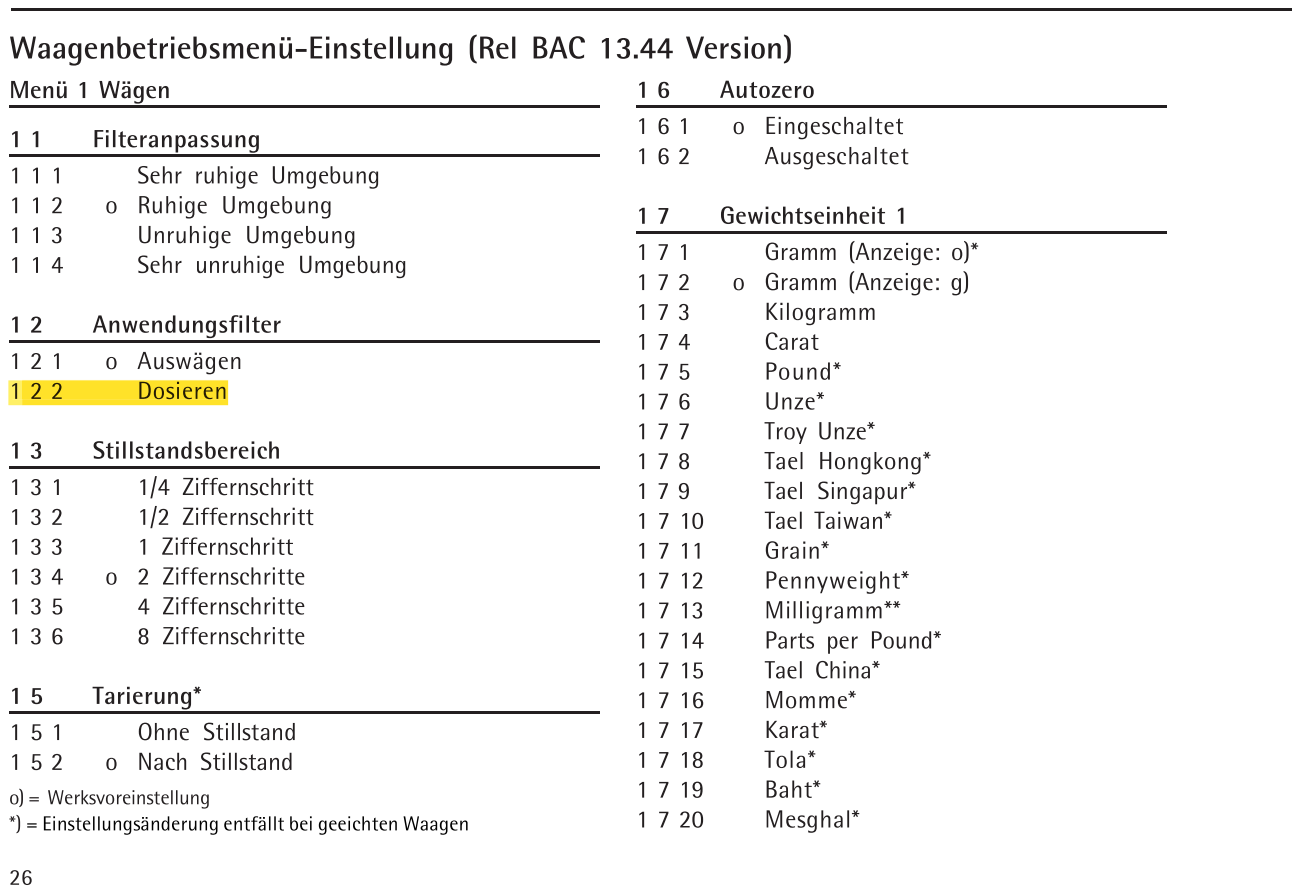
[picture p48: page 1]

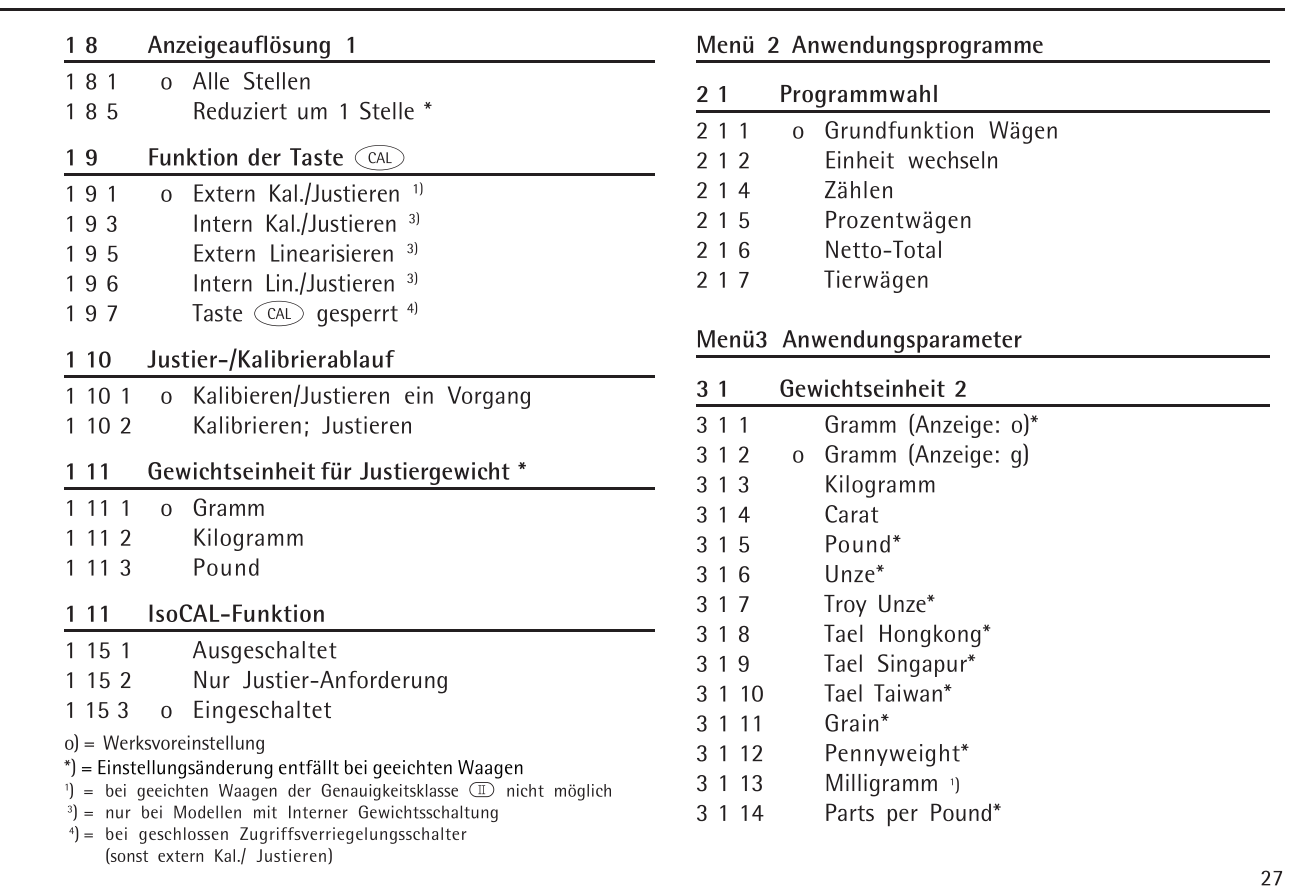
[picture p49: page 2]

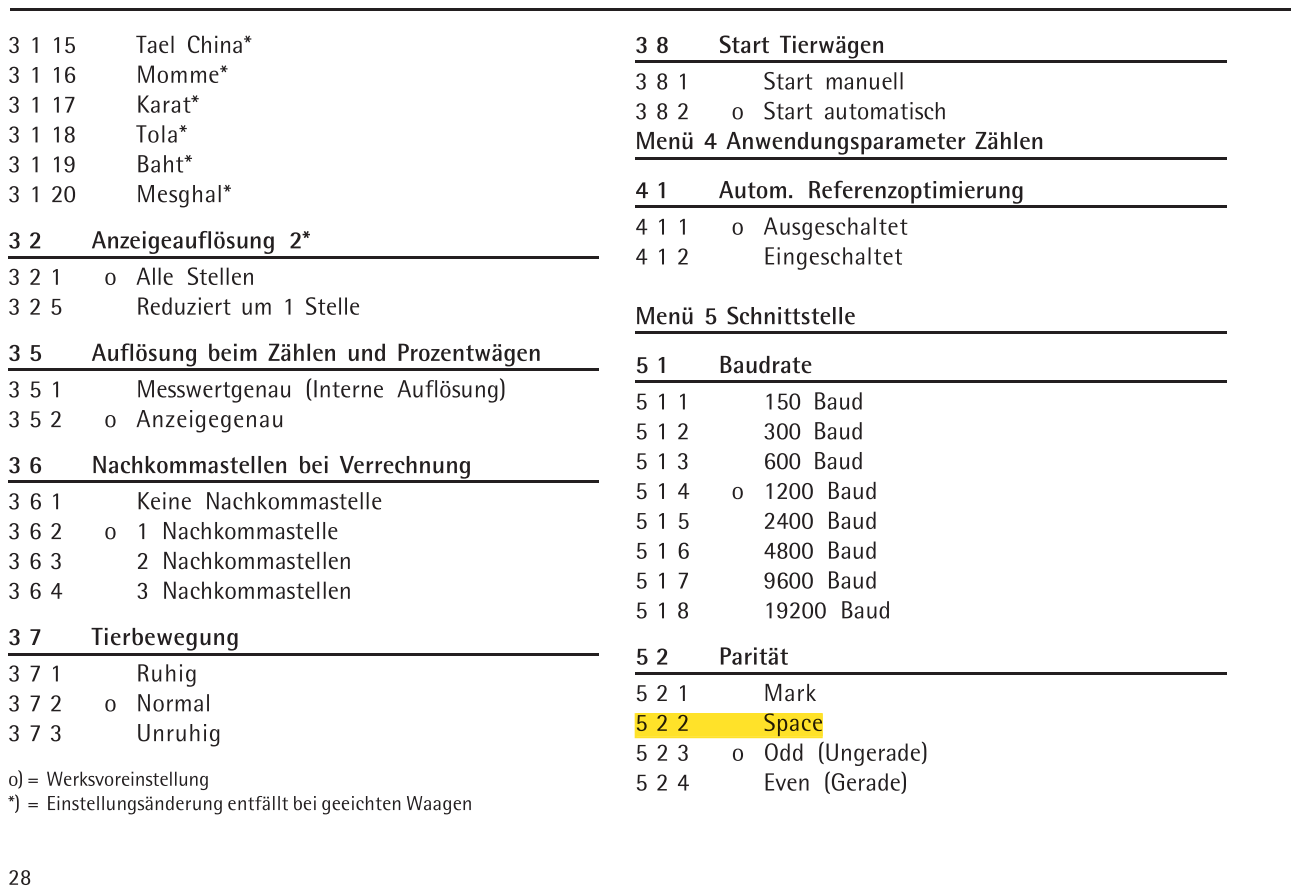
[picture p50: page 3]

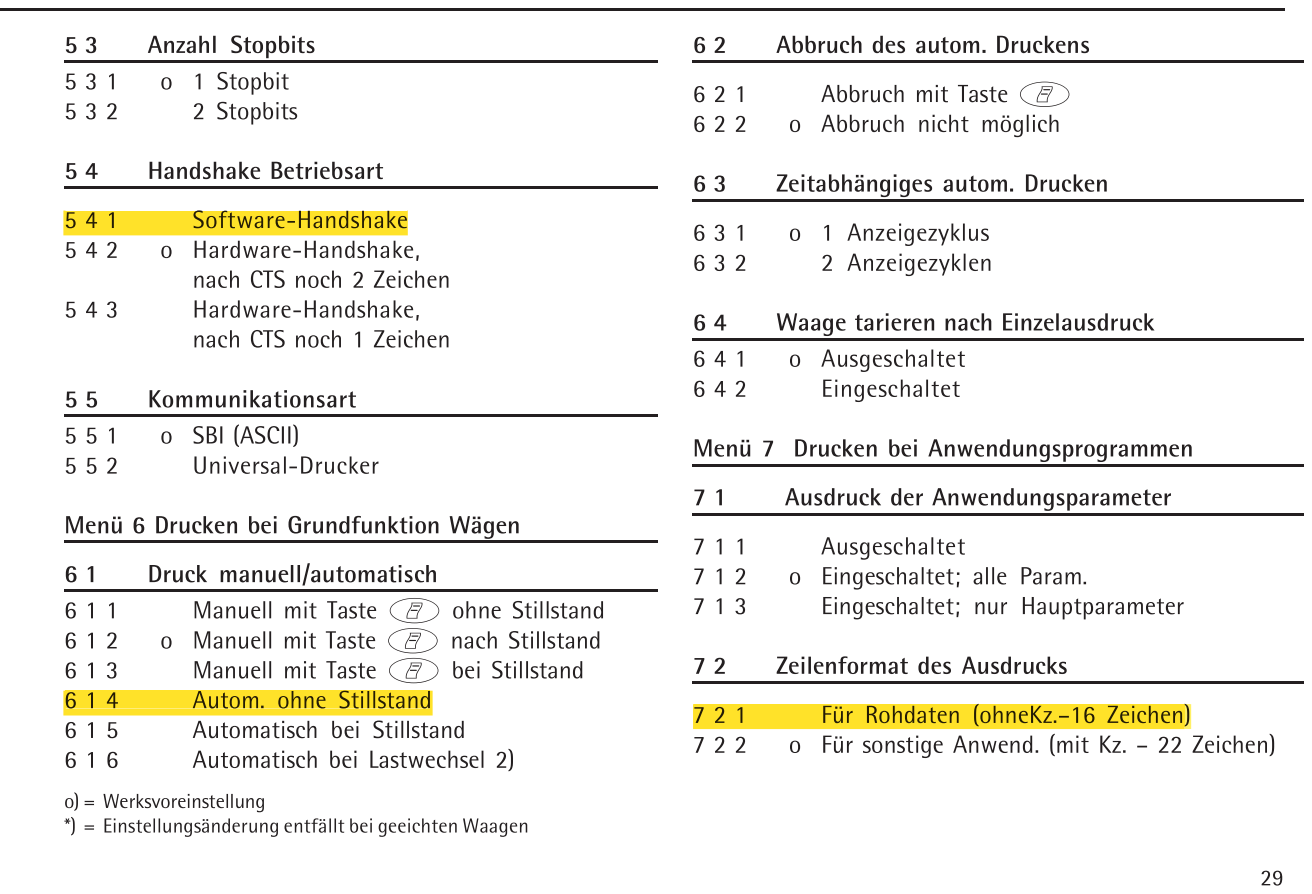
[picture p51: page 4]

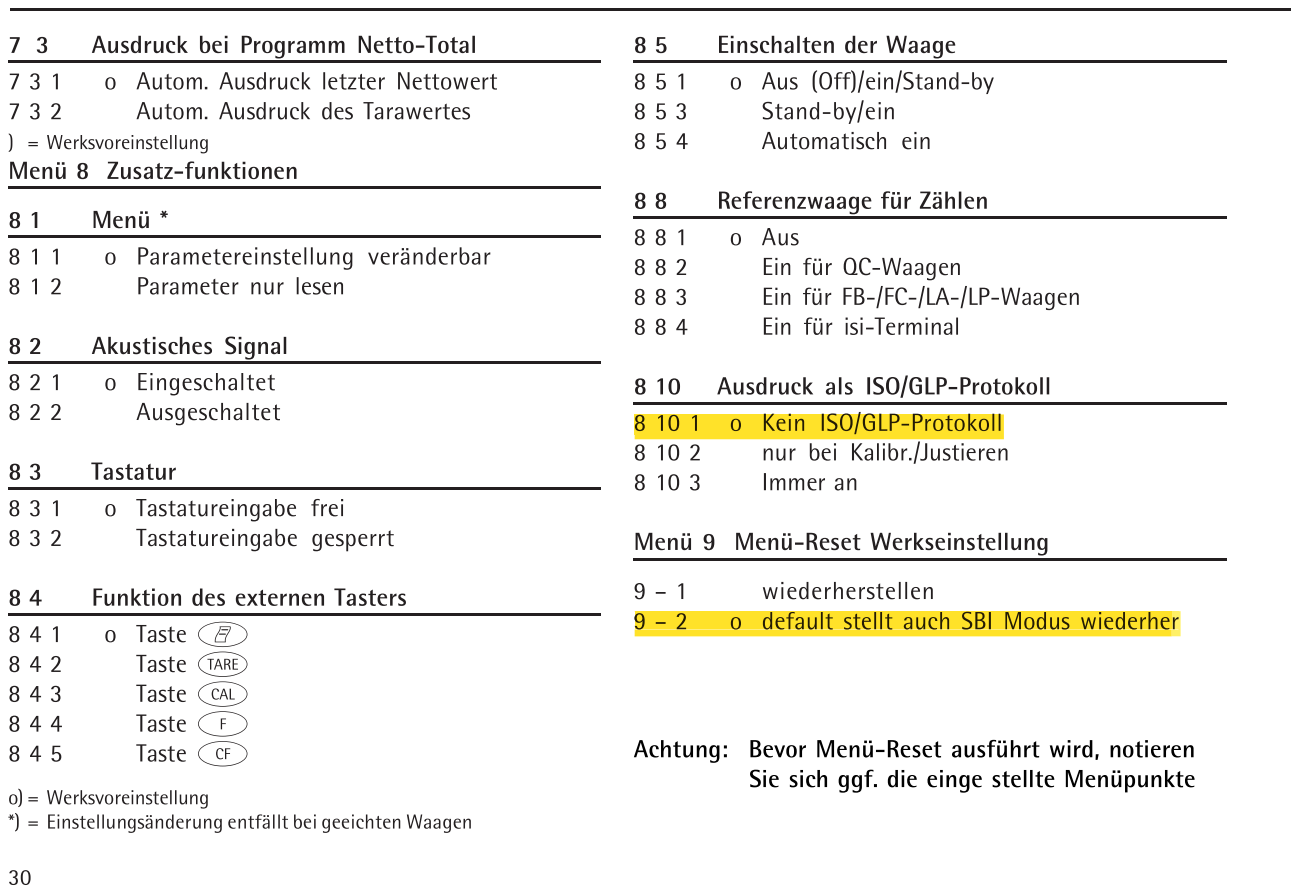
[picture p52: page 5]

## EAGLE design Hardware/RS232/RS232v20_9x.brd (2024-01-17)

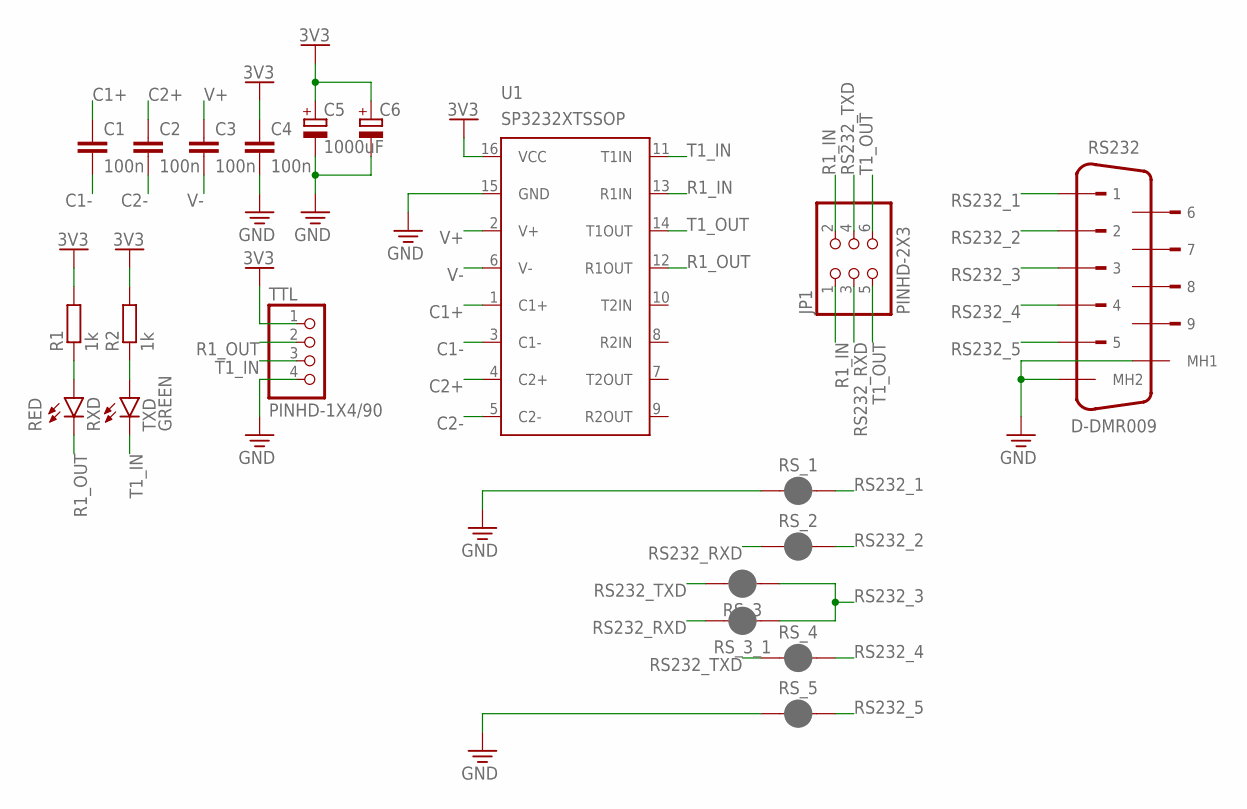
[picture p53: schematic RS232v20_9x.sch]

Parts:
C1, C2, C3, C4: 100n; C0402
C5: 1000uF; 140CLH-1010
C6: C-POL_RADIAL-11MM-DIA; CAPPRD508W65D1000H1100B
JP1: PINHD-2X3; 2X03
R1, R2: 1k; R0402
RS232: D-DMR009; 5747840-4
RS_1, RS_2, RS_3, RS_3_1, RS_4, RS_5: JUMPER-SMT_2_NC_PASTE_SILK; SMT-JUMPER_2_NC_PASTE_SILK
RXD: RED; CHIP-LED0603
TTL: PINHD-1X4/90; 1X04/90
TXD: GREEN; CHIP-LED0603
U1: SP3232XTSSOP; TSSOP16

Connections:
3V3: C4.1, C5.+, C6.1 (+), R1.2, R2.2, TTL.1, U1.16 (VCC)
C1+: C1.1, U1.1 (C1+)
C1-: C1.2, U1.3 (C1-)
C2+: C2.1, U1.4 (C2+)
C2-: C2.2, U1.5 (C2-)
GND: C4.2, C5.-, C6.2 (-), RS232.MH1 (MH2), RS232.MH2 (MH1), RS_1.1, RS_5.1, TTL.4, U1.15 (GND)
unnamed: R1.1, RXD.A
unnamed: R2.1, TXD.A
R1_IN: JP1.1, JP1.2, U1.13 (R1IN)
R1_OUT: RXD.C, TTL.2, U1.12 (R1OUT)
RS232_1: RS232.1, RS_1.2
RS232_2: RS232.2, RS_2.2
RS232_3: RS232.3, RS_3.1, RS_3_1.1
RS232_4: RS232.4, RS_4.2
RS232_5: RS232.5, RS_5.2
RS232_RXD: JP1.3, RS_2.1, RS_3_1.2
RS232_TXD: JP1.4, RS_3.2, RS_4.1
T1_IN: TTL.3, TXD.C, U1.11 (T1IN)
T1_OUT: JP1.5, JP1.6, U1.14 (T1OUT)
V+: C3.1, U1.2 (V+)
V-: C3.2, U1.6 (V-)

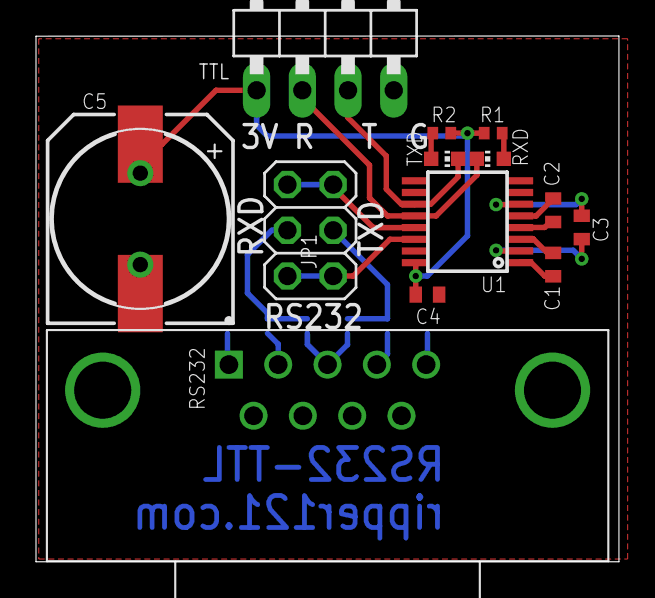
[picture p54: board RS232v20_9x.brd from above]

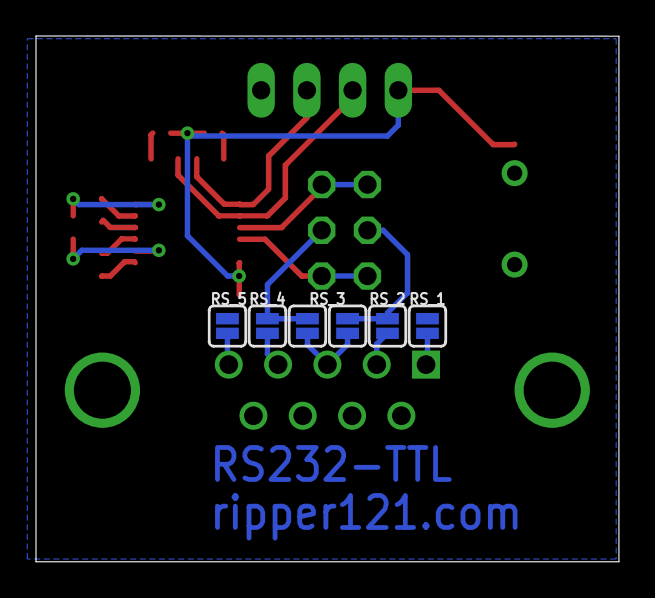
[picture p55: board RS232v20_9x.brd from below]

Board: 2 copper layers, 32.4 x 29.2 mm, 20 parts (6 on the bottom side), 21 nets.

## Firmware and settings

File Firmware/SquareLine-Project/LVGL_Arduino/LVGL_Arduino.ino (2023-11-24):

#include <lvgl.h>
#include "ui.h"
#include <TFT_eSPI.h>
#define LCD_EN GPIO_NUM_5

#define DISP_TASK_STACK 4096 * 2
#define DISP_TASK_PRO 2
#define DISP_TASK_CORE 0
TaskHandle_t lv_disp_tcb = NULL;
/*Change to your screen resolution*/
static const uint16_t screenWidth = 480;
static const uint16_t screenHeight = 320;
static lv_disp_draw_buf_t draw_buf;
static lv_color_t buf[screenWidth * screenHeight / 10];
TFT_eSPI tft = TFT_eSPI(screenWidth, screenHeight); /* TFT instance */

void trickler_start_event_cb(lv_event_t *e)
{
  if (String(lv_label_get_text(ui_LabelTricklerStart)) == "Stop")
  {
    lv_label_set_text(ui_LabelTricklerStart, "Start");
    lv_obj_set_style_bg_color(ui_ButtonTricklerStart, lv_color_hex(0x00FF00), LV_PART_MAIN | LV_STATE_DEFAULT);
  }
  else
  {
    lv_label_set_text(ui_LabelTricklerStart, "Stop");
    lv_obj_set_style_bg_color(ui_ButtonTricklerStart, lv_color_hex(0xFF0000), LV_PART_MAIN | LV_STATE_DEFAULT);
    lv_label_set_text(ui_LabelLoggerStart, "Start");
    lv_obj_set_style_bg_color(ui_ButtonLoggerStart, lv_color_hex(0x00FF00), LV_PART_MAIN | LV_STATE_DEFAULT);
  }
}

void logger_start_event_cb(lv_event_t *e)
{
  if (String(lv_label_get_text(ui_LabelLoggerStart)) == "Stop")
  {
    lv_label_set_text(ui_LabelLoggerStart, "Start");
    lv_obj_set_style_bg_color(ui_ButtonLoggerStart, lv_color_hex(0x00FF00), LV_PART_MAIN | LV_STATE_DEFAULT);
  }
  else
  {
    lv_label_set_text(ui_LabelLoggerStart, "Stop");
    lv_obj_set_style_bg_color(ui_ButtonLoggerStart, lv_color_hex(0xFF0000), LV_PART_MAIN | LV_STATE_DEFAULT);
    lv_label_set_text(ui_LabelTricklerStart, "Start");
    lv_obj_set_style_bg_color(ui_ButtonTricklerStart, lv_color_hex(0x00FF00), LV_PART_MAIN | LV_STATE_DEFAULT);
  }
}

void nnn_event_cb(lv_event_t *e)
{
  // Your code here
}

void nn_event_cb(lv_event_t *e)
{
  // Your code here
}

void n_event_cb(lv_event_t *e)
{
  // Your code here
}

void p_event_cb(lv_event_t *e)
{
  // Your code here
}

void add_event_cb(lv_event_t *e)
{
  // Your code here
}

void sub_event_cb(lv_event_t *e)
{
  // Your code here
}

void profile_event_cb(lv_event_t *e)
{
  lv_obj_clear_flag(ui_PanelMessages, LV_OBJ_FLAG_HIDDEN);
  char buffer[64];
  lv_roller_get_selected_str(ui_RollerProfile, buffer, sizeof(buffer));
  lv_label_set_text(ui_LabelMessages, buffer);
}

void message_event_cb(lv_event_t *e)
{
  lv_obj_add_flag(ui_PanelMessages, LV_OBJ_FLAG_HIDDEN);
}

IRAM_ATTR void lvgl_disp_task(void *parg)
{
  while (1)
  {
    lv_timer_handler();
  }
}

IRAM_ATTR void disp_task_init(void)
{

  xTaskCreatePinnedToCore(lvgl_disp_task,  // task
                          "lvglTask",      // name for task
                          DISP_TASK_STACK, // size of task stack
                          NULL,            // parameters
                          DISP_TASK_PRO,   // priority
                          // nullptr,
                          &lv_disp_tcb,
                          DISP_TASK_CORE // must run the task on same core
                                         // core
  );
}

void setup()
{
  Serial.begin(115200); /* prepare for possible serial debug */
  displayInit();
  ui_init();
  disp_task_init();
  Serial.println("Setup done");
}

void loop()
{
  Serial.println("Loop");
  delay(5000);
}

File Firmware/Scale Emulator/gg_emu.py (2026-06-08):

from __future__ import annotations

import random
import os
import shutil
import sys
import threading
import time
from collections import deque
from dataclasses import dataclass, field
from typing import Iterable

try:
    import msvcrt
except ImportError:  # pragma: no cover - Windows-only immediate keypress support
    msvcrt = None

try:
    import serial
    from serial.tools import list_ports
except ImportError as exc:  # pragma: no cover - only used on machines without pyserial
    raise SystemExit(
        "pyserial is required. Install it with: python -m pip install pyserial"
    ) from exc


DEFAULT_BAUD = 9600
DEFAULT_DECIMALS = 3
DEFAULT_STEP = 0.02
UNITS = ("gr", "g", "kg", "lb", "oz", "ct")

COMMANDS = {
    "p": "print",
    "q": "calibration",
    "r": "counting",
    "s": "unit",
    "t": "tare",
    "u": "backlight",
}

HELP_LINES = (
    "Console commands",
    "----------------",
    "+ / Up arrow    increase weight by the current step",
    "- / Down arrow  decrease weight by the current step",
    "w <value>       set the displayed weight, for example: w 12.345",
    "step <value>    set keypress increment/decrement size",
    "u <unit>        set unit: gr, g, kg, lb, oz, ct",
    "d <0-5>         set decimal places used in the output",
    "j <value>       set random +/- jitter added to each print",
    "print           send one weight frame, like pressing PRINT on the scale",
    "tare            set displayed weight to zero",
    "status          show current emulator state and request rate",
    "help            show this help",
    "quit            close the serial port and exit",
)


class RequestRateMeter:
    def __init__(self, window_seconds: float = 1.0) -> None:
        self.window_seconds = window_seconds
        self.timestamps: deque[float] = deque()
        self.total = 0
        self.lock = threading.Lock()

    def record(self) -> float:
        now = time.monotonic()
        with self.lock:
            self.total += 1
            self.timestamps.append(now)
            self._prune(now)
            return len(self.timestamps) / self.window_seconds

    def snapshot(self) -> tuple[float, int]:
        now = time.monotonic()
        with self.lock:
            self._prune(now)
            return len(self.timestamps) / self.window_seconds, self.total

    def _prune(self, now: float) -> None:
        cutoff = now - self.window_seconds
        while self.timestamps and self.timestamps[0] < cutoff:
            self.timestamps.popleft()


class FixedConsole:
    def __init__(self, menu_lines: Iterable[str], prompt: str = "emu> ") -> None:
        self.menu_lines = list(menu_lines)
        self.prompt = prompt
        self.input_buffer = ""
        self.log_lines: deque[str] = deque(maxlen=200)
        self.lock = threading.RLock()
        self.active = False

    def __enter__(self) -> FixedConsole:
        os.system("")
        self.active = True
        sys.stdout.write("\x1b[?1049h\x1b[?25l")
        sys.stdout.flush()
        self.render()
        return self

    def __exit__(self, exc_type, exc, traceback) -> None:
        with self.lock:
            self.active = False
            sys.stdout.write("\x1b[?25h\x1b[?1049l")
            sys.stdout.flush()

    def write(self, message: str = "") -> None:
        with self.lock:
            lines = str(message).splitlines() or [""]
            self.log_lines.extend(lines)
            self.render()

    def set_input(self, value: str) -> None:
        with self.lock:
            self.input_buffer = value
            self.render()

    def render(self) -> None:
        if not self.active:
            return

        size = shutil.get_terminal_size((100, 30))
        width = max(size.columns, 20)
        height = max(size.lines, len(self.menu_lines) + 4)
        log_height = max(1, height - len(self.menu_lines) - 2)
        visible_logs = list(self.log_lines)[-log_height:]

        lines: list[str] = []
        lines.extend(self._fit(line, width) for line in self.menu_lines)
        lines.append("-" * width)
        lines.extend(self._fit(line, width) for line in visible_logs)

        body_height = height - 1
        if len(lines) < body_height:
            lines.extend("" for _ in range(body_height - len(lines)))
        else:
            lines = lines[:body_height]

        prompt_line = self._fit(f"{self.prompt}{self.input_buffer}", width)
        sys.stdout.write("\x1b[H\x1b[2J")
        sys.stdout.write("\n".join(line.ljust(width) for line in lines))
        sys.stdout.write("\n")
        sys.stdout.write(prompt_line.ljust(width))
        sys.stdout.flush()

    @staticmethod
    def _fit(line: str, width: int) -> str:
        if len(line) <= width:
            return line
        return line[: max(0, width - 1)]
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

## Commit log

2023-06-19 Config File
    [config.txt]
2023-06-20 SD Config ready
    [config.txt]
2023-06-23 Logger & Beep Config
    [config.txt]
2023-06-25 Logger fully implemented
    [config.txt]
2023-06-26 Added README
    [CALC.ods, CALC.xls, log_1.csv]
2023-06-26 Added Webserver
    [log_040423.csv]
2023-06-28 arduino ota config
    [config.txt, log_040423.csv]
2023-08-06 Gender Changer
    No need of modifing the GUG anymore, just use a Gender Changer
    [BOM.xlsx]
2023-08-07 Stepper Fix
2023-08-07 Release 1.11
    [config.txt]
2023-08-14 v1.13
    Fixed Arduino OTA
    Added new Button for 1.0g
    GUI bigger Font, better colors
    [config.txt]
2023-08-30 3D File Update
    [Base.stl, Cap.stl, RoboTrickler.f3z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]
2023-09-02 Version 1.14
    - Measurement Unit dosen't matter anymore
    - If you change the Measurement Unit, also change the Powder Profile to the new Unit
    - fixed the configGenerator.html
    Change your last step in the Powder Profile to:
    " "10": {
    "weight": 0.000,
    "steps": 5,
    "speed": 200,
    "measurements": 25
    }
    "
    Only important thing is, you need a 0.000 last step.
    [ui.ino]
2023-09-12 Version 1.15
    - Added support for negativ weight values
    - small fixes
    - backward compatibility for G&G String
    - Unit is shown in the Display
    [ui.ino]
2023-09-25 Version 1.16
    - Added oscillate configuration
    - some display fixes
    [config.txt]
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2023-10-27 Revers & Oscillate
    - Moved oscillate from config.txt to powder.txt
    - Added Reverse to the PowderProfile
    [sd_config.ino, stepper.ino]
2023-10-27 v1.18
    - Moved Oscillate from config.txt to the PowderProfile (powder.txt)
    - added reverse to PowderProfile
    - fixed index.html
    - fixed code to work with Kern Scales
    - added Microsteps to config.txt
    - added DebugLog to config.txt
    [config.txt]
2023-11-03 Version 1.19
    - Trickler Bug Fix
    [ui.ino]
2023-11-05 New 3D Files
    [Adapter_50mm.stl, Adapter_PET.stl, Base.stl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]
2023-11-06 3d Update
    [Adapter_PET.stl, Body.stl, Stand.stl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]
2023-11-12 SD Card Creator
    [CALC.ods, CALC.xls, config.txt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]
2023-11-20 Improved UI
    [config.txt]
2023-11-21 Added StaticIP Option, Typo Fix
    [sd_config.ino, ui.ino]
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2023-11-22 Working PID and StaticIP
    [config.txt]
2023-12-01 UI Ready 2 Use
    [app2M.csv, app4M.csv]
2023-12-01 ui_TextAreaInfo Crash
    Reduce the shown characters in ui_TextAreaInfo to prevent a crash
    [RoboTricklerUI.ino]
2023-12-01 Version 2.00 with new UI
    [CALC.ods, CALC.xls, app2M.csv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]
2023-12-06 cleanup / alarm threshold
    [CALC.ods, CALC.xls, Configuring options.txt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]
2023-12-07 Updated html Generators
    [config.txt]
2023-12-07 Robo-Trickler v2.00
    - New UI
    - target weight tolerance
    - alarm for over trickle
    - many small improvements
    !!! If you come from a Firmware <2.00 you need to flash the new Firmware via USB !!!
    [RoboTricklerUI.ino, ui.ino]
2023-12-07 fixed config template
    [config.txt]
2023-12-07 Fixed Typo, Alarm Text Red
    [RoboTricklerUI.ino]
2023-12-13 Lib Update, Tolerance and Alarm moved to Profiles
    [config.txt]
2024-01-06 Update 3D Files & RS232
    [Adapter_50mm.stl, Adapter_PET.stl, Base.stl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]
2024-01-12 Fixed RS232
    [JLCSMT_CPL.xlsx]
2024-01-17 RS232 & Powder List
    [RS232v20.brd, RS232v20.sch, RS232v20_9x.brd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]
2024-01-21 Powder List & Setup Wizzard
    [PowderList.xlsx, Settings.xlsx]
2024-01-21 Changed Adapter_50mm.stl
    [Adapter_50mm.stl]
2024-02-05 3D Files optimized for Bambu Lab P1S
    [Adapter_50mm.stl, Body.stl, Cap_50mm.stl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]
2024-02-17 Moved sample profiles
    [BambuLabP1S.3mf]
2024-02-25 Update 3D Files
    [Adapter_50mm.stl, BambuLabP1S.3mf, Cap_50mm.stl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]
2024-02-26 New 3D Files & AVG Profile
    [BambuP1S_Project.3mf, PowderList.xlsx, Redding_99333_Adapter.stl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]
2024-02-26 FW Improvements & New 3D Files
    FW Improvements :
    - added Start via Webserver
    - added Stop via Webserver
    - fixed set Target Weight via Webserver
    3D Files:
    - New Riser
    - Stand Fix
    - Reservoir_Adapter Improvement
    - Body Hole for better Powder change (User a 9x19 Case for the Hole)
    [BambuP1S_Project.3mf, Body_Holed.stl, Riser_30.stl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]
2024-02-29 3D File Improved
    [Adapter_PET.stl, Body.stl, Body_Holed.stl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]
2024-03-01 Cleanup & New Trickler Web Functions.
    [Motor_Join.stl]
2024-03-05 v2.03 & 25mm Trickler
    [Body_25.stl, Fitting_25.stl, Motor_Join_25.stl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]
2024-03-06 Get Weight always from Scale
    [Settings.xlsx]
2024-03-15 feat: Add screen rotation config
    [config.txt]
2024-03-16 Small Display FIx
    [Body_25.stl, Fitting_25.stl, Motor_Join_25.stl]
2024-03-16 Revert "Merge branch 'main' of https://github.com/ripper121/RoboTrickler"
    This reverts commit a99646fef7c1d2a99d02272bfcd114e46a468bf8, reversing
    changes made to fb8cf387e7d8991dbf83e06e69b2c1b51f5d2590.
    [config.txt]
2024-03-18 25mm Ready to use
    [Body_25.stl, Fitting_25.stl]
2024-03-28 Screen FIx
    [config.txt]
2024-04-07 RS232 Update
    [RS232v19.sch, RS232v19_9x.sch, RS232v20.brd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]
2024-04-09 Small fix
    [Settings.xlsx, config.txt]
2024-05-12 Awacs Mod
    [Adapter_PET.stl, Body mod Awacs.stp, Body.stl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]
2024-05-27 acceleration & fw_check, some fixes
    [RoboTricklerUI.ino, sd_config.ino, stepper.ino]
2024-05-31 4mm Holes Stand
    [Riser_30.stl, Riser_30mm.stl, Stand.stl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]
2024-06-03 Latest Config and new Binarys
    [config.txt]
2024-06-16 small fixes
    [Stand.stl, config.txt]
2024-06-16 RS232 Cleanup
    [BOM_JLCSMT.xlsx, RS232v19.sch, RS232v19_9x.sch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]
2024-06-25 ConfigGenerator & Max Target
    [partitions.csv]
2024-07-11 Fixed Tolerance, Added Color to Weight
    [RoboTricklerUI.ino, sd_config.ino, stepper.ino]
2024-07-11 Lib Update
    [Configuring options.txt]
2024-07-18 New Trickler Designe & 70 mm Powder Tank
    [BodyTilt2Deg.stl, New_Stand.stl, Reservoir_Adapter_70mm.stl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]
2024-08-07 New 3D Files & SD-Card Image
    [Body.stl, BodyDefault_DIY.stl, BodyTilt2Deg.stl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]
2024-10-08 Fixed TargetWeight Save Bug
    [RoboTricklerUI.ino]
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2024-11-29 3D File Mods
    [Adapter_PET.stl, Body mod Awacs.stp, Body.stl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]
2024-12-03 BugFix
    If the profile which was defined in the config.txt is not found, calibrate.txt will be used.
    [RoboTricklerUI.ino, sd_config.ino]
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2024-12-27 Protocol readout fix, calibration fix, firstThrow fix
    [RoboTricklerUI.ino, sd_config.ino]
2025-01-12 TargetWeight Fix
    [Powder_Roof_Half.stl]
2025-01-27 Enclosure for Control Unit by marwaw-ops
    https://github.com/ripper121/RoboTrickler/issues/3
    https://github.com/marwaw-ops
    [Settings.xlsx]
2025-08-30 New RS232
    [B6B-PH-K-S(LF)(SN).STEP, B6B-XH-A-LF--SN---3DModel-STEP-418109.STEP, BOM_JLCSMT.xlsx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]
2026-03-29 ESP-IDF Version
    [partitions.csv]
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2026-04-10 Clean Compile
    [Configuring options.txt, partitions.csv]
2026-04-11 Version 2.09
    No Touch Gestures
    [partitions.csv]
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2026-04-28 IDF Version beta
    [partitions.csv]
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2026-04-30 new Profile
    [CALC.ods, CALC.xls, PowderList.xlsx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]
2026-04-30 replaced stepper lib
2026-05-04 FW Update URL
    [config.txt]
2026-05-11 New Enclosure
    [Back.stl, Base.stl, Display0.stl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]
2026-05-12 general actuator
    [config.txt]
2026-05-28 wifi and webserver fixes
    [RoboTricklerUI.ino]
2026-06-04 global Trickle counter & reboot button for editor
    [config.txt]
2026-06-04 update changelog and manual
    [config_full.txt]
2026-06-09 fix lang, removed screenshot
    [sd_config.ino, ui.ino]
2026-06-09 reboot web ui fix
    [RoboTricklerUI.ino]
2026-06-11 Revert "extract tar"
    This reverts commit 2e3bc0cf48383190ceccf7476af0e26900403ac9.
    [RoboTricklerUI.ino]
2026-06-11 CAD Update
    [Adapter.stl, Adapter_PET.stl, Back.stl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]
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2026-06-12 reverted LVGL Messagebox, back to my impl
    [RoboTricklerUI.ino, display_task.ino, firmware_check.ino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]
2026-06-13 Release 2.12
    [config.txt]
2026-06-13 Version 2.13 LittleFS Flash
    [app2M.csv, config.txt, partitions.csv]
2026-06-14 profile tweaks
    [config.txt]
2026-06-14 New features
    [config.txt]
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2026-06-14 Wifi QR Code, Wifi Toggle
    [config.txt]
2026-06-14 UI Dialog Bug Fixes
    [display_helpers.ino, startup.ino, ui_dialogs.ino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]
2026-06-14 UI fixes
    Completed the deep UI pass and fixed:
    Stale dialogs during web-triggered actions.
    False running-state button after failed startup.
    Repeated web starts and profile changes while running.
    Dialog and long-label overflow.
    Invalid-profile message clipping.
    Cross-core log-buffer and debug LVGL access races.
    Weight color not resetting after stop.
    [config.txt]
2026-06-14 2.13 Release Bin
    [config.txt]
2026-06-17 SD-Card Speed fix, LittleFS space save
    [config.txt]
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2026-06-19 renamed speed to rpm
    [config.txt]
2026-06-23 naming audit
    [config.txt]
2026-06-23 better struct of json files
    [config.txt]
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2026-07-06 Always apply profile-step RPM (fix bulk-move RPM carryover)
    setStepperRpm() only assigns steppers[n].rpm, which step() reads and which persists across runs. The removed setStepperRpmIfChanged() cache went stale after runBulkStepperMove() called setStepperRpm() directly, so a fine step whose RPM matched the cached value was skipped and ran at the bulk RPM instead - dumping powder too fast and over-trickling. Apply the RPM on every profile step and drop the pointless cache.
    [trickler_runtime.ino]
2026-07-06 Reset targetWeight when loading a profile without one
    loadProfile() reset every other profile field before applying the file but left targetWeight untouched, so a profile that omits general.targetWeight silently inherited the previously loaded profile target. Reset it to the standard 40.0 default first, matching the rest of the reset block and setDefaultConfiguration().
    [sd_storage.ino]
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2026-07-06 Service captive-portal DNS and reject mid-run web target edits
    Pump dnsServer.processNextRequest() while the WiFi setup AP is active so
    captive-portal clients resolve and get redirected. Reject /setTarget with
    409 while trickling to avoid racing config.targetWeight from Core 0.
    [display_task.ino, web_api.ino]
2026-07-06 Fix trickler bugs and centralize the weight domain (0.0000-500.0000)
    Bug fixes:
    - Guard the on-screen +/- target buttons against mid-run edits, matching
    the web API: config.targetWeight is read live by the Core 1 state machine.
    - Stop passing the user-editable translation to snprintf as a format string
    in the filesystem sync message; substitute only a literal %d safely.
    - Skip profile next/previous navigation when the list is empty (no -1 index,
    no pointless load/save cycle).
    - Drop the dead tautological branch in firmwareCheckUrl().
    Weight domain refactor:
    - Add a single source of truth (WEIGHT_DECIMALS / WEIGHT_MIN / WEIGHT_MAX /
    WEIGHT_RESOLUTION) plus weightToString()/formatWeig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
    [RoboTricklerUI.ino, display_helpers.ino, filesystem_sync.ino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]
2026-07-06 Route profile-step selection through the weight-comparison helper
    selectProfileStep() used a raw float <= comparison, the only weight
    threshold test that bypassed the tolerance-aware helpers; use
    weightAtOrBelow() so every comparison shares one epsilon. Also decouple
    WEIGHT_STEP_SIZES from WEIGHT_RESOLUTION, making it a plain decade ladder.
    [RoboTricklerUI.ino, trickler_runtime.ino]
2026-07-06 Remove dead code and dedupe profile/lang/dialog helpers
    - Drop unused stringToIPAddress(), MAX_TARGET_WEIGHT, the write-only
    lastWeight global, warnBox()/COLOR_MSG_WARNING, and the transitive
    WiFiClient/WiFiUdp includes.
    - Add loadProfileDocument() and route saveProfileTargetWeight() through
    writeProfileDocument(), removing the duplicated temp-file swap.
    - Extract normalizedLanguageCode() shared by loadLanguage()/loadWebLang().
    - Add dismissMessageDialog() to unify the message/confirm close path.
    - Collapse the trickler state dispatch switch into grouped cases.
    [RoboTricklerUI.ino, scale_rs232.ino, sd_storage.ino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]
2026-07-07 Fix trickler/web bugs and reduce SD wear, heap churn, and UI stalls
    - Abort Start when the selected profile was recovered onto calibrate so a
    corrupt/missing profile can no longer launch an unrequested calibration throw
    - Defer config.txt writes while browsing profiles; persist on Start and
    explicitly on profile delete/create
    - Make /api/wifi/scan asynchronous (202 + polling AP page) so the shared
    LVGL/web task no longer freezes during scans
    - Replace String unit buffers in readWeight()/readScaleLine() with fixed
    char buffers (allocation-free scale read loop)
    - Create web-editor files empty instead of writing a stray NUL byte
    - Use a non-blocking dialog for the max-profiles error rea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
    [RoboTricklerUI.ino, display_helpers.ino, filesystem_mount.ino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]
2026-07-07 Drive the stepper shift register with the I2S peripheral (DMA)
    Replace the bit-banged shift-register driver with the ESP32 I2S peripheral
    in MSB stereo mode: 32-bit state words stream MSB-first at 125 kHz frames
    (one latch per 8 us), so step pulses are DMA-paced with zero CPU jitter and
    the old ~tens-of-microseconds-per-step digitalWrite() ceiling is gone.
    - A feeder task streams the live state word between moves so enable/
    direction/beeper writes keep working through the same ordered stream
    - step() takes the stream mutex and writes the whole pulse train; blocking
    DMA writes pace the move, preserving its blocking semantics
    - DMA buffers are preloaded with the safe idle state (disable b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
    [stepper.ino, ui_text.ino]
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2026-09-07 bin update
    [partitions.csv]
2026-09-10 Add profile tuning and update user documentation
    - support compact profiles with defaults and a configurable trickle-map limit factor
    - limit generated calibration profiles to powder_1 through powder_32 and remove the legacy config filename exclusion
    - update the profile editor, translations, sample profiles, filesystem images, and release binaries
    - expand the end-user manual, integrate the quick start, and document SD updates, Access Point operation, and offline tools
    [partitions.csv]
2026-09-15 RS232 Files
    [BOM_JLCSMT.xlsx, Electronics Design.csv, Electronics Design.f3z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]
2026-09-17 Step Test Button
    [Lee.stl, Roof.stl, RoofLee.stl]
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2026-09-27 Screen Rotation and Web Editor
    [config.txt]

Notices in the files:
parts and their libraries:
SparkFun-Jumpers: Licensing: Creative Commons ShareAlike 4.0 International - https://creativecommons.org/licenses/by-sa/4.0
